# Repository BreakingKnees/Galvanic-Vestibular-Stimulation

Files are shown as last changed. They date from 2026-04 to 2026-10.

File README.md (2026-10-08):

# Galvanic Vestibular Stimulation (GVS): Clinical Hardware Architecture

**Status: 🚧 Active Research & Hardware Development**

This repository documents the engineering progression of a miniature, battery-operated Galvanic Vestibular Stimulation (GVS) neural interface. The primary objective of this project is to develop a safe, sub-sensory, strictly charge-balanced hardware architecture capable of modulating the tonic firing rate of the vestibular nerve without inducing electrochemical hazards.

While the system includes a zero-latency UDP software telemetry bridge for control, the current development focus is strictly on **analog circuit design, physiological safety, and ethical stimulation protocols** necessary to transition from a theoretical proof-of-concept to a clinically viable medical device.

---

## 🔬 Clinical Safety & Ethical Design Directives

Interfacing directly with the human vestibular system requires absolute adherence to electro-physiological safety limits. A core focus of this repository is eliminating the risks associated with standard hobbyist electronics:
* **Strict Charge-Balancing (True AC):** Eliminating continuous direct current (DC) to prevent ion accumulation, localized tissue polarization, and chemical burns at the electrode-skin interface.
* **Voltage-Controlled Constant Current (VCCS):** Human skin impedance fluctuates wildly (e.g., due to perspiration). The hardware must dynamically adjust voltage to maintain a locked, predictable current output, neutralizing the risk of sudden current spikes.
* **Hardware-Level Fault Limits:** Software cannot be the sole safety barrier. The architecture enforces absolute maximum current limits via physical passive components to protect the user in the event of a microcontroller crash.

---

## 🛠️ Hardware Evolution & Schematic Log

The project's analog architecture is evolving iteratively to address strict clinical requirements. *Below is the current state of development, followed by archived legacy iterations.*

### Phase 2: Biphasic VCCS Architecture
**Status:** Active Theoretical Design & Electro-Mathematical Review

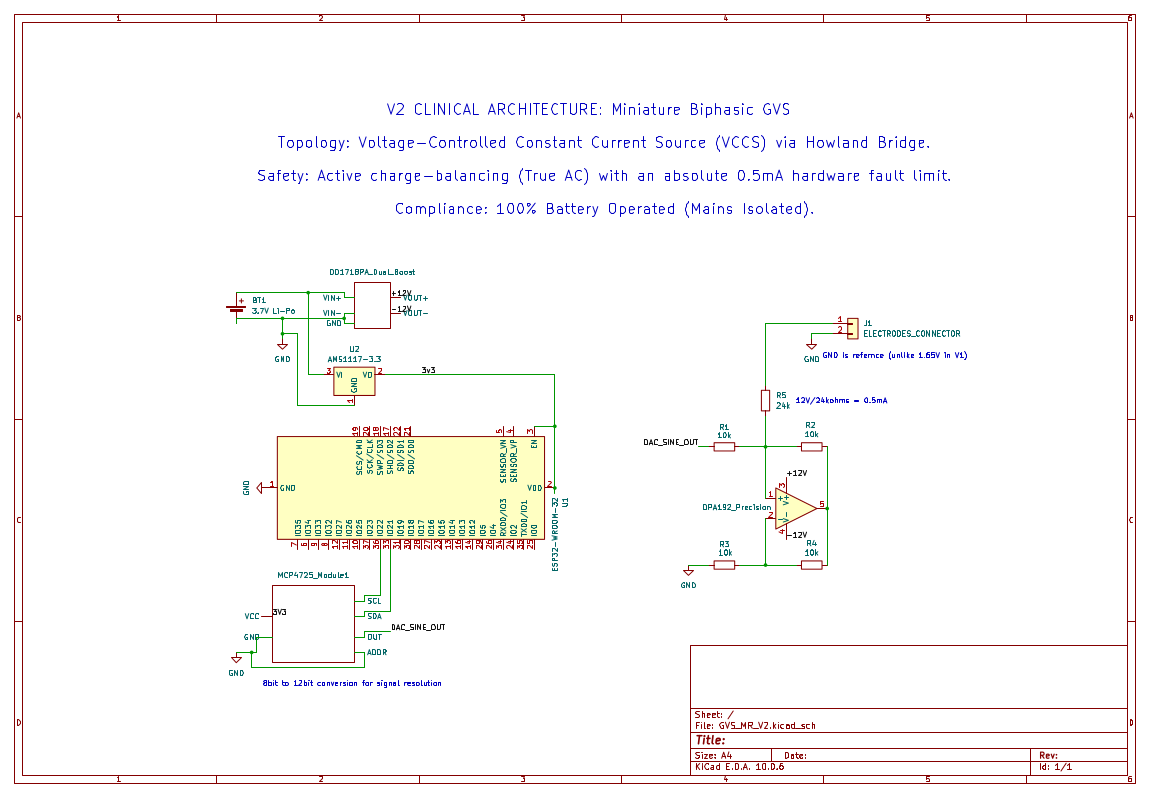
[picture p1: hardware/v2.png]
V2 Schematic


* **Architecture:** A complete topological overhaul shifting from a voltage source to a Voltage-Controlled Constant Current Source (VCCS) via a Howland Current Pump bridge. The design utilizes an OPA192 precision op-amp.
* **Signal Precision:** Waveform generation is offloaded to an external I2C 12-bit DAC (MCP4725) to ensure sub-sensory, high-resolution sine waves.
* **Power Topology:** Utilizes a dual-boost module (DD1718PA) to generate true +/-12V rails from a 3.7V Li-Po, establishing the groundwork for true AC charge-balancing. A 24kΩ limiting resistor was placed in series with the load to mathematically cap the maximum output at 0.5mA.
* **Identified Roadblocks for V3 PCB Revision:**
  Rigorous mathematical review of V2 flagged critical compliance issues currently being addressed for the next iteration:
  1. **Power Starvation:** The AMS1117-3.3 LDO regulator possesses a dropout voltage incompatible with Li-Po discharge curves, risking ESP32 brownouts. *Resolution: Migrating to a CMOS ultra-low dropout (LDO) regulator.*
  2. **The Biphasic Paradox:** V2 grounds the inverting pin. Because the DAC is unipolar (0-3.3V), the current cannot swing negative. *Resolution: Reintroducing the 1.65V virtual ground to shift the baseline for true AC output.*
  3. **Compliance Voltage Starvation:** Pushing 0.5mA through the 24kΩ safety resistor plus human skin resistance requires ~17V, which will clip on the +/-12V rails, introducing high-frequency harmonic distortion. *Resolution: Lowering the safety resistor and utilizing active diode clamping.*
  4. **Hardware DC-Blocking:** The architecture requires physical output capacitors to strictly block DC injection during a fault state.

### Phase 1: Monophasic Wearable Prototype
**Status:** Archived 

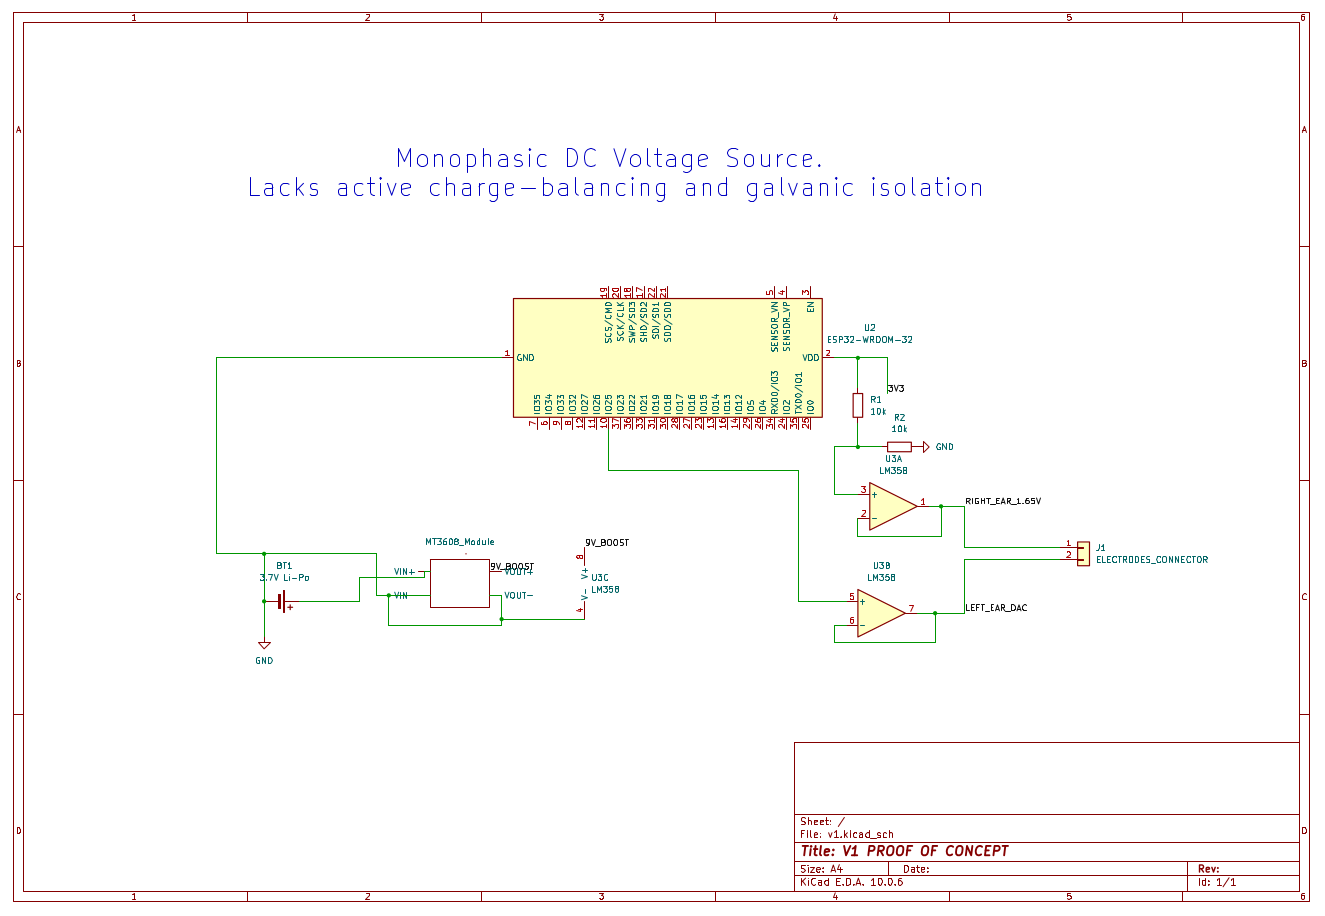
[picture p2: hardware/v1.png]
V1 Schematic


* **Architecture:** Transitioned to a fully portable wearable powered by a 3.7V Li-Po battery. Employed an MT3608 boost converter and established a 1.65V virtual ground using an LM358 op-amp to allow bidirectional control logic.
* **Clinical Limitations (Electrochemical Hazard):** The circuit functioned as a unipolar DC voltage source without active charge-balancing. Extended use risks severe skin polarization. Furthermore, operating as a voltage source meant any natural drop in skin resistance would result in an uncontrolled, hazardous spike in delivered current.

### Phase 0: Initial Bench Validation
**Status:** Archived (In-Vitro Testing Only)

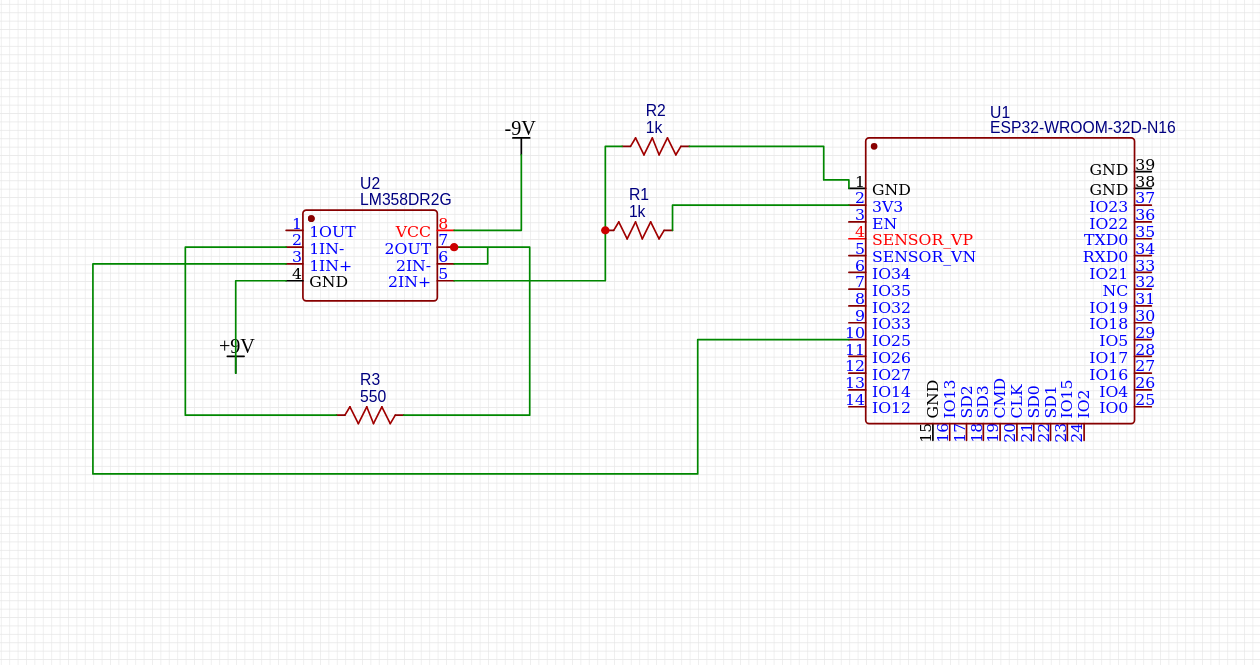
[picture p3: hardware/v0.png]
V0 Schematic


* **Architecture:** A rudimentary unregulated voltage source utilizing an ESP32-WROOM-32D microcontroller and an LM358DR2G op-amp.
* **Power Supply:** Tethered to external +/- 9V bench power supplies.
* **Clinical Limitations:** This iteration lacked galvanic isolation, utilized a low-resolution internal 8-bit DAC (causing jagged, physically irritating voltage spikes), and possessed zero current-limiting mechanisms. Unsuitable for human deployment.

---

## 📡 Telemetry & Control Bridge

While hardware safety is the primary focus, the system relies on a high-performance digital pipeline for stimulus triggering:
* **The ESP32 Neural Engine:** Receives vector data via UDP protocols to ensure zero-latency execution.
* **Python Command Bridge:** A Flask-based backend captures user input and formats it into telemetry packets for the microcontroller.
* *(Note: Telemetry codebase is located in the `/src` directory, pending updates following the finalization of the V3 hardware architecture).*

---

## 🎓 Project Origins

This architecture was originally conceptualized and rapidly prototyped during Hacknite by Zense (by Aaditya Khanna and Anand S.Menon) at the International Institute of Information Technology, Bangalore (IIITB), where it was awarded 1st Place in the IoT Track. The project is currently being re-engineered by Aaditya Khanna to meet rigorous clinical safety standards.

> **Disclaimer:** This repository contains open-source schematics for educational and experimental purposes in neural interfacing and analog circuit design. Interfacing with biological systems carries inherent risks. Ethical safety protocols, galvanic isolation, and strict current-limiting hardware must be thoroughly validated prior to any in-vivo application.

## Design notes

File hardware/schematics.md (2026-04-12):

# Hardware Implementation: Analog Current Source

To interface with the vestibular nerve safely and effectively, we cannot use standard PWM (Pulse Width Modulation) as the frequency is too sharp for biological systems. We require a true, proportional Analog Voltage.

## Component Stack
1. **Microcontroller:** ESP32 (Utilizing the internal 8-bit DAC on Pin 25).
2. **Amplifier:** LM358 Non-Inverting Operational Amplifier.
3. **Safety/Feedback:** 500Ω Resistor Chain.

## Wiring & Logic
The circuit is designed around a **1.65V Virtual Ground**. In a standard circuit, current flows from positive to ground. By biasing our neutral state to 1.65V (exactly half of our 3.3V logic level), we create a "push-pull" dynamic on a single wire.

* **ESP32 Pin 25 (DAC) -> Op-Amp Non-Inverting Input (+)**
* **Op-Amp Output -> 500Ω Resistor -> Electrode A**
* **Electrode B -> 1.65V Virtual Ground**

## The "Seesaw" Effect (Modulating Firing Rates)
When the user's joystick is centered, the DAC outputs a value of 128 (~1.65V). The net current across the electrodes is 0mA.
* **Steering Left (DAC < 128):** Voltage drops below 1.65V. Current flows in reverse (Cathodal stimulation), depolarizing the nerve and *increasing* the tonic firing rate.
* **Steering Right (DAC > 128):** Voltage rises above 1.65V. Current flows forward (Anodal stimulation), hyperpolarizing the nerve and *decreasing* the firing rate.

Current flow ($I$) is continuously monitored and calculated via: `I = (V_out - 1.65) / 500`

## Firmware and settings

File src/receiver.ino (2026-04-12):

#include <WiFi.h>
#include <WiFiUdp.h>

// --- Network Configuration ---
const char* ssid = "YOUR_SSID_HERE";
const char* password = "YOUR_PASSWORD_HERE";

// --- Hardware Configuration ---
WiFiUDP udp;
char packetBuffer[255];
const int dacPin = 25; // GPIO 25 is DAC1 on ESP32
const int udpPort = 4210;

// Variables for Telemetry
int currentX = 0; 

void setup() {
  Serial.begin(115200);
  
  // Initialize Wi-Fi connection
  WiFi.begin(ssid, password);
  while (WiFi.status() != WL_CONNECTED) {
    delay(500);
    Serial.print(".");
  }
  
  Serial.println("\n[CONNECTED]");
  Serial.print("Local IP: ");
  Serial.println(WiFi.localIP());
  
  // Start UDP listener
  udp.begin(udpPort);
}

void loop() {
  // Check for incoming UDP packets from the Python Bridge
  int packetSize = udp.parsePacket();
  if (packetSize) {
    int len = udp.read(packetBuffer, 255);
    if (len > 0) packetBuffer[len] = 0;
    
    String msg = String(packetBuffer);
    
    // Parse the X-vector data (Format: "X:value")
    if (msg.startsWith("X:")) {
      currentX = msg.substring(2).toInt(); // Expected range: -127 to 127
    }
  }

  // --- Op-Amp Control Logic ---
  // Map joystick (-127 to 127) to DAC (0 to 255)
  // Neutral (0) maps to 128 (~1.65V) to establish the Virtual Ground bias
  int dacValue = map(currentX, -127, 127, 0, 255);
  dacWrite(dacPin, dacValue);

  // --- Telemetry Math ---
  float currentVoltage = (dacValue / 255.0) * 3.3;
  
  // Current (mA) calculation based on 500-ohm feedback resistor
  // Formula: I = (V_out - V_ref) / R
  float current_mA = ((currentVoltage - 1.65) / 500.0) * 1000.0;

  // Real-time Serial Output for Debugging/Documentation
  Serial.print("Vector: "); Serial.print(currentX);
  Serial.print(" | DAC: "); Serial.print(dacValue);
  Serial.print(" | Voltage: "); Serial.print(currentVoltage, 2);
  Serial.print("V | Current: "); Serial.print(current_mA, 2);
  Serial.println(" mA");

  delay(10); // Maintain stability for the Serial buffer
}

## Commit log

2026-04-14 Clarify hardware-limited power supply section
    Revised the description of the hardware-limited power supply for clarity and safety details.
2026-10-08 docs: archive V0 initial bench testing schematic and identify clinical limitations
2026-10-08 hw: commit V1 monophasic wearable KiCad schematic and document skin polarization hazards
    [v1.kicad_sch]
2026-10-08 hw: introduce V2 biphasic VCCS KiCad schematic, 12-bit DAC integration, and V3 compliance roadblocks
    [v2.kicad_sch]
2026-10-08 chore: organize repository structure by moving hardware files and renaming requirements.txt
    [v1.kicad_sch, v2.kicad_sch]
